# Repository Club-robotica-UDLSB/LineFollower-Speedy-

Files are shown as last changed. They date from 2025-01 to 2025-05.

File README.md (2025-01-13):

# LineFollower-Speedy-
Documentación del desarrollo del Seguidor de línea (El speedy)  

```plaintext
line_follower_project/
├── docs/                        # Documentación del proyecto
│   ├── README.md                # Descripción del proyecto
│   ├── schematics/              # Diagramas eléctricos y electrónicos
│   │   ├── circuit_diagram.png
│   │   └── PCB_design.pdf
│   └── requirements.md          # Lista de requisitos de hardware y software
├── hardware/                    # Archivos relacionados con el hardware
│   ├── BOM.csv                  # Lista de materiales (Bill of Materials)
│   ├── chassis_design/          # Diseños mecánicos (CAD)
│   │   ├── chassis.stl
│   │   └── chassis.fusion360
│   ├── sensors/                 # Información sobre sensores
│   │   └── sensor_datasheets/
│   │       └── IR_sensor.pdf
│   ├── motor_drivers/           # Archivos de controladores de motores
│   │   └── motor_driver_schematic.png
│   └── microcontroller/         # Configuración del microcontrolador
│       ├── pinout_diagram.png
│       └── firmware.hex
├── software/                    # Código fuente y programas
│   ├── main/                    # Código principal
│   │   ├── main.c
│   │   └── main.h
│   ├── libraries/               # Librerías reutilizables
│   │   ├── PID_controller.c
│   │   └── motor_control.c
│   ├── test/                    # Código para pruebas
│   │   ├── test_pid_controller.c
│   │   └── test_sensors.c
│   └── README.md                # Guía para compilar e instalar
├── tests/                       # Pruebas físicas y simulaciones
│   ├── simulations/             # Simulaciones virtuales
│   │   └── line_follower_simulation.py
│   ├── performance_logs/        # Registros de pruebas de rendimiento
│   │   ├── test_1_results.log
│   │   └── test_2_results.log
│   └── README.md                # Guía de pruebas
├── media/                       # Fotos, videos y otros recursos multimedia
│   ├── videos/
│   │   └── demo_video.mp4
│   └── images/
│       ├── prototype.jpg
│       └── testing.jpg
├── LICENSE                      # Licencia del proyecto
├── README.md                    # Introducción y explicación del proyecto
├── .gitignore                   # Archivos y carpetas a ignorar por Git
└── Makefile                     # Configuración para compilar el proyecto
```

## Descripción de las Carpetas y Archivos

### `docs/`
- **`README.md`**: Descripción general del proyecto.
- **`schematics/`**: Contiene diagramas eléctricos y diseños de PCB.
- **`requirements.md`**: Detalla los requisitos de hardware y software.

### `hardware/`
- **`BOM.csv`**: Lista de materiales necesarios para el proyecto.
- **`chassis_design/`**: Archivos de diseño mecánico del chasis.
- **`sensors/`**: Información técnica sobre los sensores utilizados.
- **`motor_drivers/`**: Esquemáticos de controladores de motores.
- **`microcontroller/`**: Configuración y firmware del microcontrolador.

### `software/`
- **`main/`**: Código principal del proyecto.
- **`libraries/`**: Librerías reutilizables (como controladores PID o control de motores).
- **`test/`**: Scripts para probar diferentes partes del sistema.

### `tests/`
- **`simulations/`**: Contiene simulaciones virtuales del robot.
- **`performance_logs/`**: Registros de pruebas realizadas en el hardware.

### `media/`
- **`videos/`**: Videos de demostración o pruebas del robot.
- **`images/`**: Fotos del prototipo, resultados de pruebas, etc.

### Archivos Raíz
- **`LICENSE`**: Licencia del proyecto.
- **`README.md`**: Introducción al proyecto.
- **`.gitignore`**: Archivos o carpetas que Git debe ignorar.
- **`Makefile`**: Instrucciones para compilar y ejecutar el proyecto.

---

## Notas Adicionales

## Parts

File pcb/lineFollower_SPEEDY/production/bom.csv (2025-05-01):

Designator | Footprint | Quantity | Value | LCSC Part #
C1, C4, C7, C9 | 0603 | 4 | 10uF
C10, C2, C3, C5 | 0603 | 4 | 1uF
C6, C8 | 0603 | 2 | 0.1uF
D1 | 1206 | 1 | LED
D2 | D_DO-41_SOD81_P10.16mm_Horizontal | 1 | 1N5817
DEV_BOARD1 | Electrosmith_Daisy_Seed | 1 | Black_pill_stm32f411
J1, J2 | JST_PH_S2B-PH-K_1x02_P2.00mm_Horizontal | 2 | 3.7v 2000mAh
J3, J4 | PinHeader_1x08_P2.54mm_Horizontal | 2 | Conn_01x08_Pin
J5 | PinHeader_2x03_P2.54mm_Vertical | 1 | Serie-Paralelo
M1, M2 | motor | 2 | GA12-N20
MOD1 | DRV8833_mod | 1 | DRV8825_breakout
PSB1, PSB2 | SX1308_mod | 2 | SX1308_module
Q1 | SOT-23 | 1 | MMBT5550L
R1, R10, R11, R12, R13, R4, R6, R7 | 0805 | 8 | 220
R14, R15, R16, R17, R2, R20, R21, R5, R8, R9 | 0805 | 10 | 10k
R18 | 0805 | 1 | 150
R19 | 0805 | 1 | 1k
R24 | 0805 | 1 | 100
R3 | 0805 | 1 | 330
RV1 | Potentiometer_Bourns_3296W_Vertical | 1 | 500
SW1, SW2 | SW_Tactile_SPST_NO_Straight_CK_PTS636Sx25SMTRLFS | 2 | SW_Push
SW3 | SW_Slide-03_Wuerth-WS-SLTV_10x2.5x6.4_P2.54mm | 1 | ON-OFF
TP1 | TestPoint_Loop_D2.54mm_Drill1.5mm_Beaded | 1 | TestPoint_voltaje_Motores
TP2 | TestPoint_Loop_D2.54mm_Drill1.5mm_Beaded | 1 | TestPoint_5V
TP3 | TestPoint_Loop_D2.54mm_Drill1.5mm_Beaded | 1 | TestPoint_IRleds
U1, U2, U3, U4, U5, U6, U7, U8 | QRD1114 | 8 | QRD1114
U10 | SOT-223-3_TabPin2 | 1 | LM1117MP-ADJ
U11 | SSOP-24_5.3x8.2mm_P0.65mm | 1 | CD74HC4067SM
U12, U9 | SOT-223-3_TabPin2 | 2 | AMS1117-3.3
U13 | ESP-01 | 1 | ESP-01S
U14 | SOT-223-3_TabPin2 | 1 | AMS1117-5.0

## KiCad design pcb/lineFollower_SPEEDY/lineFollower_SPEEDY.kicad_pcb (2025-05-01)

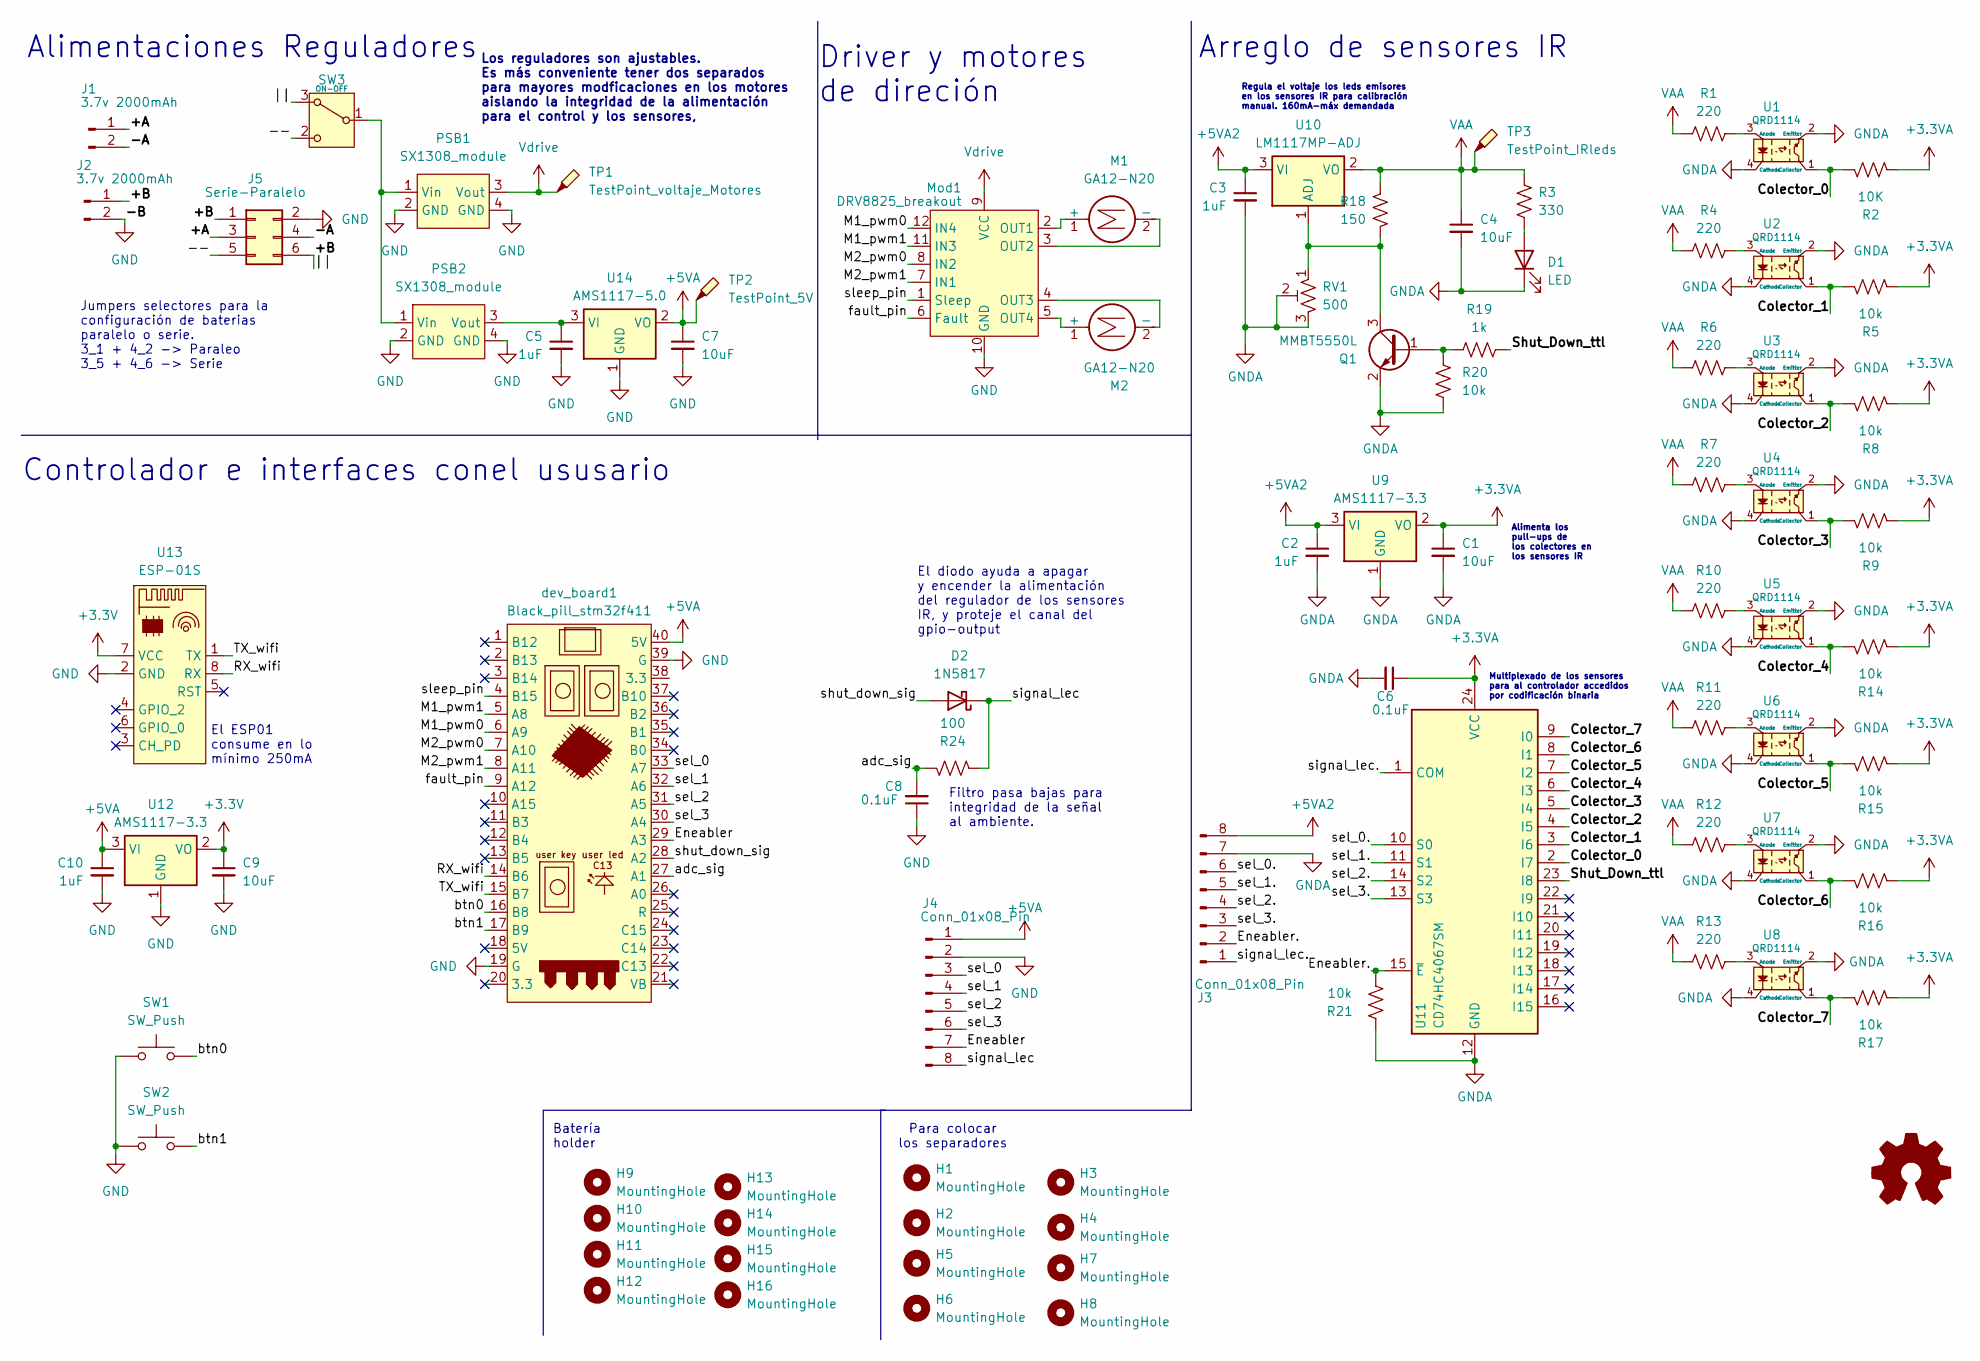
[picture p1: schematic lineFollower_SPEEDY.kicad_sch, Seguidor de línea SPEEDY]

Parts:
C1, C4, C7, C9: 10uF; C_0603_1608Metric_Pad1.08x0.95mm_HandSolder
C2, C3, C5, C10: 1uF; C_0603_1608Metric_Pad1.08x0.95mm_HandSolder
C6, C8: 0.1uF; C_0603_1608Metric_Pad1.08x0.95mm_HandSolder
D1: LED; LED_1206_3216Metric_Pad1.42x1.75mm_HandSolder
D2: 1N5817; D_DO-41_SOD81_P10.16mm_Horizontal
H1, H2, H3, H4, H5, H6, H7, H8, H9, H10, H11, H12, H13, H14, H15, H16: MountingHole; MountingHole_2.2mm_M2
J1, J2: 3.7v 2000mAh; JST_PH_S2B-PH-K_1x02_P2.00mm_Horizontal
J3, J4: Conn_01x08_Pin; PinHeader_1x08_P2.54mm_Horizontal
J5: Serie-Paralelo; PinHeader_2x03_P2.54mm_Vertical
M1, M2: GA12-N20; motor
Mod1: DRV8825_breakout; DRV8833_mod
PSB1, PSB2: SX1308_module; SX1308_mod
Q1: MMBT5550L; SOT-23
R1, R4, R6, R7, R10, R11, R12, R13: 220; R_0805_2012Metric_Pad1.20x1.40mm_HandSolder
R2: 10K; R_0805_2012Metric_Pad1.20x1.40mm_HandSolder
R3: 330; R_0805_2012Metric_Pad1.20x1.40mm_HandSolder
R5, R8, R9, R14, R15, R16, R17, R20, R21: 10k; R_0805_2012Metric_Pad1.20x1.40mm_HandSolder
R18: 150; R_0805_2012Metric_Pad1.20x1.40mm_HandSolder
R19: 1k; R_0805_2012Metric_Pad1.20x1.40mm_HandSolder
R24: 100; R_0805_2012Metric_Pad1.20x1.40mm_HandSolder
RV1: 500; Potentiometer_Bourns_3296W_Vertical
SW1, SW2: SW_Push; SW_Tactile_SPST_NO_Straight_CK_PTS636Sx25SMTRLFS
SW3: ON-OFF; SW_Slide-03_Wuerth-WS-SLTV_10x2.5x6.4_P2.54mm
TP1: TestPoint_voltaje_Motores; TestPoint_Loop_D2.54mm_Drill1.5mm_Beaded
TP2: TestPoint_5V; TestPoint_Loop_D2.54mm_Drill1.5mm_Beaded
TP3: TestPoint_IRleds; TestPoint_Loop_D2.54mm_Drill1.5mm_Beaded
U1, U2, U3, U4, U5, U6, U7, U8: QRD1114
U9, U12: AMS1117-3.3; SOT-223-3_TabPin2
U10: LM1117MP-ADJ; SOT-223-3_TabPin2
U11: CD74HC4067SM; SSOP-24_5.3x8.2mm_P0.65mm
U13: ESP-01S; ESP-01
U14: AMS1117-5.0; SOT-223-3_TabPin2
dev_board1: Black_pill_stm32f411; Electrosmith_Daisy_Seed

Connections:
+3.3V: C9.1, U12.2 (VO), U13.7 (VCC)
+3.3VA: C1.1, C6.1, R2.2, R5.2, R8.2, R9.2, R14.2, R15.2, R16.2, R17.2, U9.2 (VO), U11.24 (VCC)
+5VA: C7.1, C10.1, J4.1, TP2.1, U12.3 (VI), U14.2 (VO), dev_board1.40 (5V)
+5VA2: C2.1, C3.1, J3.8, U9.3 (VI), U10.3 (VI)
/+A: J1.1, J5.3
/+B: J2.1, J5.1, J5.6, SW3.3 (A)
/--: J5.5, SW3.2 (C)
/-A: J1.2, J5.4
/Colector_0: R2.1, U1.1 (Collector), U11.2 (I7)
/Colector_1: R5.1, U2.1 (Collector), U11.3 (I6)
/Colector_2: R8.1, U3.1 (Collector), U11.4 (I5)
/Colector_3: R9.1, U4.1 (Collector), U11.5 (I4)
/Colector_4: R14.1, U5.1 (Collector), U11.6 (I3)
/Colector_5: R15.1, U6.1 (Collector), U11.7 (I2)
/Colector_6: R16.1, U7.1 (Collector), U11.8 (I1)
/Colector_7: R17.1, U8.1 (Collector), U11.9 (I0)
/Eneabler: J4.7, dev_board1.29 (A3)
/Eneabler.: J3.2, R21.2, U11.15 (~E)
/M1_pwm0: Mod1.12 (IN4), dev_board1.6 (A9)
/M1_pwm1: Mod1.11 (IN3), dev_board1.5 (A8)
/M2_pwm0: Mod1.8 (IN2), dev_board1.7 (A10)
/M2_pwm1: Mod1.7 (IN1), dev_board1.8 (A11)
/RX_wifi: U13.8 (RX), dev_board1.14 (B6)
/Shut_Down_ttl: R19.1, U11.23 (I8)
/TX_wifi: U13.1 (TX), dev_board1.15 (B7)
/adc_sig: C8.2, R24.2, dev_board1.27 (A1)
/btn0: SW1.2, dev_board1.16 (B8)
/btn1: SW2.2, dev_board1.17 (B9)
/fault_pin: Mod1.6 (Fault), dev_board1.9 (A12)
/sel_0: J4.3, dev_board1.33 (A7)
/sel_0.: J3.6, U11.10 (S0)
/sel_1: J4.4, dev_board1.32 (A6)
/sel_1.: J3.5, U11.11 (S1)
/sel_2: J4.5, dev_board1.31 (A5)
/sel_2.: J3.4, U11.14 (S2)
/sel_3: J4.6, dev_board1.30 (A4)
/sel_3.: J3.3, U11.13 (S3)
/shut_down_sig: D2.2 (A), dev_board1.28 (A2)
/signal_lec: D2.1 (K), J4.8, R24.1
/signal_lec.: J3.1, U11.1 (COM)
/sleep_pin: Mod1.1 (Sleep), dev_board1.4 (B15)
GND: C5.2, C7.2, C8.1, C9.2, C10.2, J2.2, J4.2, J5.2, Mod1.10 (GND), PSB1.2 (GND), PSB1.4 (GND), PSB2.2 (GND), PSB2.4 (GND), SW1.1, SW2.1, U12.1 (GND), U13.2 (GND), U14.1 (GND), dev_board1.19 (G), dev_board1.39 (G)
GNDA: C1.2, C2.2, C3.2, C4.2, C6.2, D1.1 (K), J3.7, Q1.2 (E), R20.2, R21.1, RV1.2, RV1.3, U1.2 (Emitter), U1.4 (Cathode), U2.2 (Emitter), U2.4 (Cathode), U3.2 (Emitter), U3.4 (Cathode), U4.2 (Emitter), U4.4 (Cathode), U5.2 (Emitter), U5.4 (Cathode), U6.2 (Emitter), U6.4 (Cathode), U7.2 (Emitter), U7.4 (Cathode), U8.2 (Emitter), U8.4 (Cathode), U9.1 (GND), U11.12 (GND)
unnamed: D1.2 (A), R3.1
unnamed: M1.1 (+), Mod1.2 (OUT1)
unnamed: M1.2 (-), Mod1.3 (OUT2)
unnamed: M2.1 (+), Mod1.5 (OUT4)
unnamed: M2.2 (-), Mod1.4 (OUT3)
unnamed: PSB1.1 (Vin), PSB2.1 (Vin), SW3.1 (B)
unnamed: C5.1, PSB2.3 (Vout), U14.3 (VI)
unnamed: Q1.1 (B), R19.2, R20.1
unnamed: Q1.3 (C), R18.1, RV1.1, U10.1 (ADJ)
unnamed: R1.2, U1.3 (Anode)
unnamed: R4.2, U2.3 (Anode)
unnamed: R6.2, U3.3 (Anode)
unnamed: R7.2, U4.3 (Anode)
unnamed: R10.2, U5.3 (Anode)
unnamed: R11.2, U6.3 (Anode)
unnamed: R12.2, U7.3 (Anode)
unnamed: R13.2, U8.3 (Anode)
VAA: C4.1, R1.1, R3.2, R4.1, R6.1, R7.1, R10.1, R11.1, R12.1, R13.1, R18.2, TP3.1, U10.2 (VO)
Vdrive: Mod1.9 (VCC), PSB1.3 (Vout), TP1.1

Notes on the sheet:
Driver y motores de direción
Multiplexado de los sensores para al controlador accedidos por codificación binaria
El ESP01 consume en lo mínimo 250mA
El diodo ayuda a apagar y encender la alimentación del regulador de los sensores IR, y proteje el canal del gpio-output
Alimenta los pull-ups de los colectores en los sensores IR
Arreglo de sensores IR
Los reguladores son ajustables. Es más conveniente tener dos separados para mayores modficaciones en los motores aislando la integridad de la alimentación para el control y los sensores,
Regula el voltaje los leds emisores en los sensores IR para calibración manual. 160mA-máx demandada
Batería holder
Jumpers selectores para la configuración de baterias paralelo o serie. 3_1 + 4_2 -> Paraleo 3_5 + 4_6 -> Serie
Filtro pasa bajas para integridad de la señal al ambiente.
Alimentaciones Reguladores
Controlador e interfaces conel ususario
Para colocar los separadores

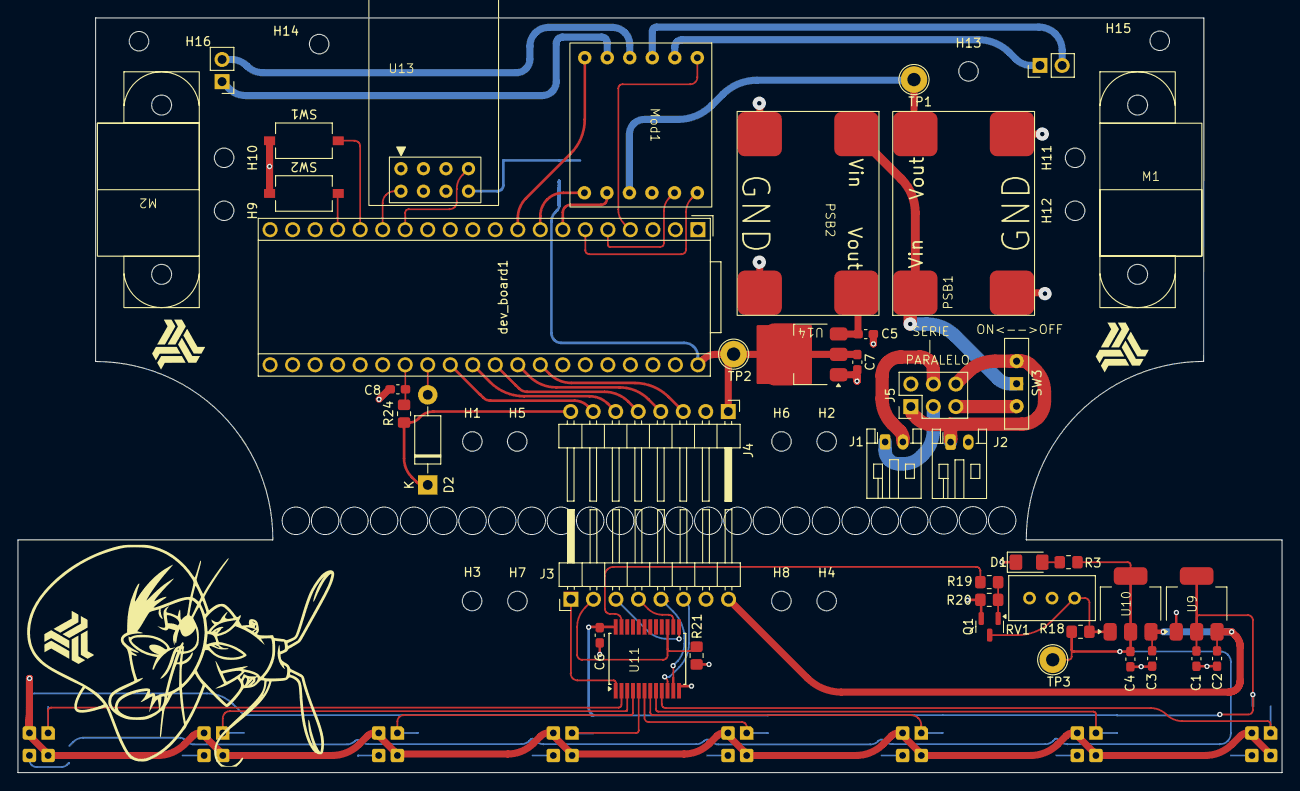
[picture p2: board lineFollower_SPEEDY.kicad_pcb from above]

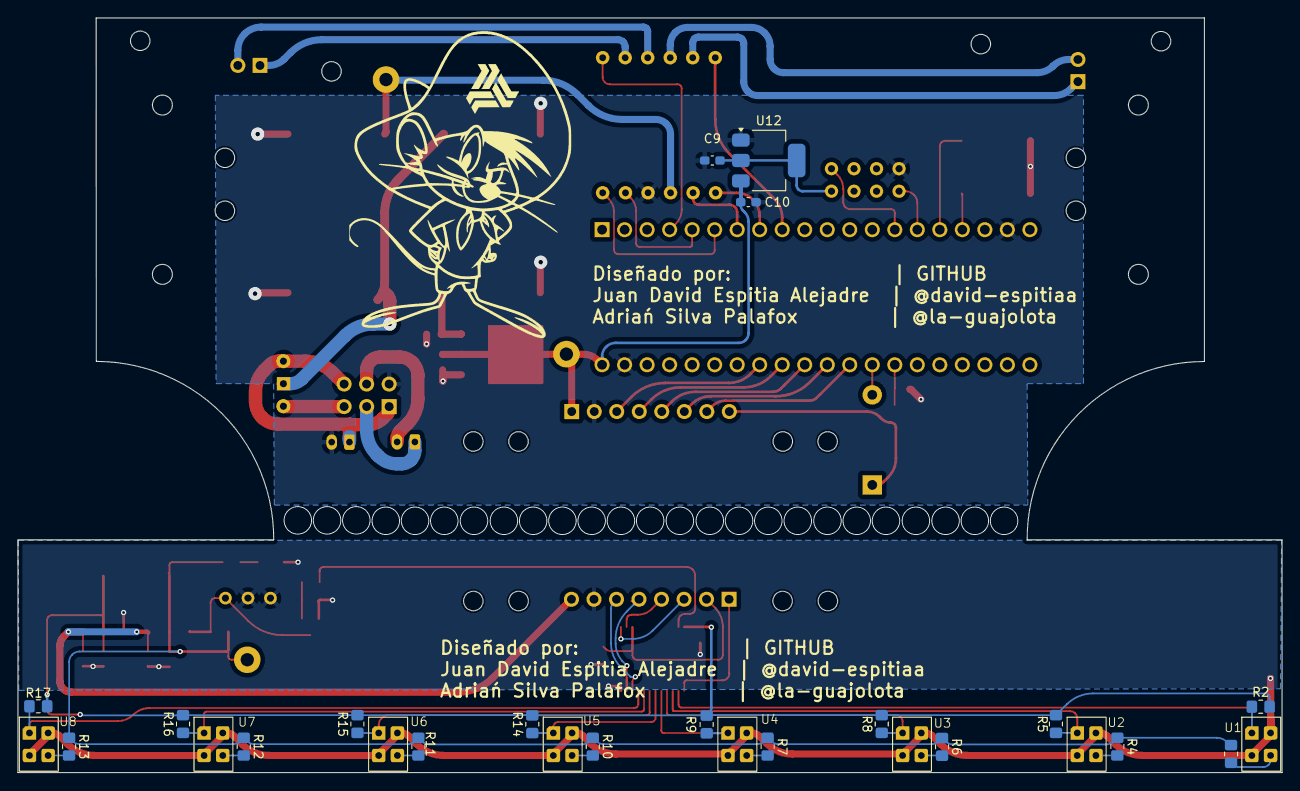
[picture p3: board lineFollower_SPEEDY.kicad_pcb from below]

Board: 2 copper layers, 142.6 x 85.1 mm, 83 parts (27 on the bottom side), 62 nets.

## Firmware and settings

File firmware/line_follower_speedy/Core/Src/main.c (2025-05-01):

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
/* Includes ------------------------------------------------------------------*/
#include "main.h"

/* USER CODE BEGIN Includes */
#include <math.h>
#include <stdlib.h>
// Line follower's hardware and software libraries
#include "fuzzy.h"
#include "pid.h"
#include "esp01.h"
#include "DRV8833.h"
#include "array_ir_sensor.h"
/* USER CODE END Includes */

ADC_HandleTypeDef hadc1;

TIM_HandleTypeDef htim1;
TIM_HandleTypeDef htim3;

UART_HandleTypeDef huart1;
DMA_HandleTypeDef hdma_usart1_rx;
DMA_HandleTypeDef hdma_usart1_tx;

/* USER CODE BEGIN PV */
/* UART COMMUNICATION TO ESP01*/
char TXbuffer[80];      			// TX uart buffer
volatile uint8_t RXuart_size = 1;	// Size of data to handle DMA
char RXbuffer[20];      			// RX uart buffer
char* pend_buff;     				// character end pointer
char pos_buff; 			 			// Buffer index
volatile bool TXuart_flag = true; 	// DMA uart_tx data sent completed flag
volatile bool RXuart_flag = false; 	// DMA uart_rx data sent completed flag
/* PID CONTROLLER */
PIDController pid;
const float setpoint = 0.0;
/* Fuzzy controller */
/* Line follower parameters */
volatile bool pid_flag = false;
float IRsense = 0.0;
uint8_t motorPWM = 0;
uint16_t IRsarray[IR_SENSORS];
float IRsarray_norm[IR_SENSORS];
const float weights[] =
{
		-0.95,  //IR0
		-0.8,   //IR1
		-0.56,  //IR2
		-0.21,  //IR3
		0.21,   //IR4
		0.56,   //IR5
		0.8,    //IR6
		0.95,   //IR7
};

/* USER CODE END PV */

void SystemClock_Config(void);
static void MX_GPIO_Init(void);
static void MX_DMA_Init(void);
static void MX_TIM1_Init(void);
static void MX_ADC1_Init(void);
static void MX_USART1_UART_Init(void);
static void MX_TIM3_Init(void);
/**
  * @brief  The application entry point.
  * @retval int
  */
int main(void)
{

  /* MCU Configuration--------------------------------------------------------*/

  /* Reset of all peripherals, Initializes the Flash interface and the Systick. */
  HAL_Init();

  /* Configure the system clock */
  SystemClock_Config();

  /* Initialize all configured peripherals */
  MX_GPIO_Init();
  MX_DMA_Init();
  MX_TIM1_Init();
  MX_ADC1_Init();
  MX_USART1_UART_Init();
  MX_TIM3_Init();
  /* USER CODE BEGIN 2 */

  // Initiate motors
  /* PWM channels for motor driver */
  HAL_TIM_PWM_Start(&htim1,TIM_CHANNEL_1);
  HAL_TIM_PWM_Start(&htim1,TIM_CHANNEL_2);
  HAL_TIM_PWM_Start(&htim1,TIM_CHANNEL_3);
  HAL_TIM_PWM_Start(&htim1,TIM_CHANNEL_4);
  stop_motors();

  //Initiate PID controller
  pid.limMin = -100;    	//Output's minimum limit
  pid.limMax = 100;     	//Output's maximum limit
  pid.limMinInt = -10.0;    //Integrator's minimum limit
  pid.limMaxInt = 10.0;  	//Integrator's maximum limit
  pid.T = 0.001;		    //Sample time in seconds
  pid.tau = pid.T*0.5;      //Derivative low-pass filter time constant
  PIDController_Init(&pid);

  // Initialize communication with ESP01
  ESP01_StatusTypeDef status = esp01_init();
  if(status == ESP01_OK) esp01_udp_start();
  if(status == ESP01_OK) esp01_start_uart_transparent();
  if(status == ESP01_OK) HAL_UART_Receive_DMA(&huart1, (uint8_t*)RXbuffer, RXuart_size);
  /*
  //Debug
  if(status == ESP01_OK){
	HAL_Delay(10000);
	// 1,2,3,4,5,6,7,8,9 ASCII coded
	for (uint8_t var = 48; var < 58; ++var) {
		HAL_UART_Transmit(&huart1, &var, 1, 1);
	}
	esp01_end_uart_transparent();
  }
  */
  //CALIBRATE
  enable_mux(true);
  enable_ldo(true);
  HAL_TIM_Base_Start_IT(&htim3);

  /* USER CODE END 2 */

  /* Infinite loop */
  /* USER CODE BEGIN WHILE */
  while (1)
  {
    /* USER CODE END WHILE */

    /* USER CODE BEGIN 3 */
    // FUZZY PID CONTROLLER
	if (pid_flag) {
		pid_flag = false;

		//Sense IRs
		sense_IR (IRsarray);

		//NORMALIZATION AND WEIGHTING  ->>  CALCULATE ROBOT POSITION AND ORENTATION
		IRsense = 0;
		for (int var = 0; var < IR_SENSORS; ++var) {
			IRsarray_norm[var] = normal_min_max((float)IRsarray[var], 0, 4095) * weights[var];
			IRsense += IRsarray_norm[var];
		}

		//IR SENSORS PATTERN RECOGNITION
		//Fuzzy
		//PID
		PIDController_Update(&pid, setpoint, IRsense);

		//ACT ON MOTORS
		motorPWM = (uint8_t)fabsf(pid.out);

		if (IRsense < 0) { // Turn <--
			motors(dir_a,motorPWM);
		} else if (IRsense > 0) { // Turn -->
			motors(dir_b,motorPWM);
		} else { // Go forward
			motors(dir_c,motorPWM);
		}
	 }

	//Parsing recollected date to send via UDP
	if (status == ESP01_OK && TXuart_flag == true) {
		TXuart_flag = false;
		// Buffer index let us start from "S" on
		pos_buff = snprintf(TXbuffer, sizeof(TXbuffer), "M%dE%.2fS", motorPWM, IRsense);
		// Append the IRsarray_norm[] values
		for (int i = 0; i < IR_SENSORS; i++) {
			pos_buff += snprintf(TXbuffer + pos_buff, sizeof(TXbuffer) - pos_buff, ",%.2f", IRsarray_norm[i]);
		}
		// FOR DEBUGING -> strcat(TXbuffer,RXbuffer);
		HAL_UART_Transmit_DMA(&huart1,(uint8_t*)TXbuffer,strlen(TXbuffer));
	}

	//Parsing RXbuffer and update PID gains
	if (RXuart_flag == true && RXuart_size == 1) {
		RXuart_flag = false;
		switch (RXbuffer[0]) {
			case 'P':
				pid.Kp = strtof(RXbuffer + 1,NULL);
				break;
			case 'I':
				pid.Ki = strtof(RXbuffer + 1,NULL);
				break;
			case 'D':
				pid.Kd = strtof(RXbuffer + 1,NULL);
				break;
		}
	}

  }
  /* USER CODE END 3 */
}

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
/* USER CODE BEGIN 4 */

// DMA CALLBACKS
// It is needed to have the NVIC uart activated, otherwise it wont receive the interrupt
void HAL_UART_TxCpltCallback(UART_HandleTypeDef *huart){
	TXuart_flag = true; //Enables STATE_MACHINE_UDP_SEND
}

void HAL_UART_RxCpltCallback(UART_HandleTypeDef *huart){

	if (RXuart_flag) {
		// We mark the end of valid information to parse
		RXbuffer[RXuart_size] = '\0';
		// We receive one byte first to determine the amount of data to be handled
		RXuart_size = 1; // this variable is also used as a flag
		HAL_UART_Receive_DMA(&huart1, (uint8_t*)RXbuffer, RXuart_size);
	} else {
		RXuart_size = (uint8_t)(RXbuffer[0]);//New data length DMA will wait for
		HAL_UART_Receive_DMA(&huart1, (uint8_t*)RXbuffer, RXuart_size);
		RXuart_flag = true;
	}
}

// ISR TIMER
void HAL_TIM_PeriodElapsedCallback(TIM_HandleTypeDef* htim){
	pid_flag = true;
}

/* USER CODE END 4 */
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


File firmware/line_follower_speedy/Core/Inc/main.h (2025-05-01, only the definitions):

#define led_user_Pin GPIO_PIN_13
#define led_user_GPIO_Port GPIOC
#define builtint_btn_Pin GPIO_PIN_0
#define builtint_btn_GPIO_Port GPIOA
#define ttl_ldo_Pin GPIO_PIN_2
#define ttl_ldo_GPIO_Port GPIOA
#define mux_en_Pin GPIO_PIN_3
#define mux_en_GPIO_Port GPIOA
#define muxchn_3_Pin GPIO_PIN_4
#define muxchn_3_GPIO_Port GPIOA
#define muxchn_2_Pin GPIO_PIN_5
#define muxchn_2_GPIO_Port GPIOA
#define muxchn_1_Pin GPIO_PIN_6
#define muxchn_1_GPIO_Port GPIOA
#define muxchn_0_Pin GPIO_PIN_7
#define muxchn_0_GPIO_Port GPIOA
#define sleep_mode_Pin GPIO_PIN_15
#define sleep_mode_GPIO_Port GPIOB
#define M1_1_Pin GPIO_PIN_8
#define M1_1_GPIO_Port GPIOA
#define M1_0_Pin GPIO_PIN_9
#define M1_0_GPIO_Port GPIOA
#define M2_0_Pin GPIO_PIN_10
#define M2_0_GPIO_Port GPIOA
#define M2_1_Pin GPIO_PIN_11
#define M2_1_GPIO_Port GPIOA
#define fault_Pin GPIO_PIN_12
#define fault_GPIO_Port GPIOA
#define fault_EXTI_IRQn EXTI15_10_IRQn

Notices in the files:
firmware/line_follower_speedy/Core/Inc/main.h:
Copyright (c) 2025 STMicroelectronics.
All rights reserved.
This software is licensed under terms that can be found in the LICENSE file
